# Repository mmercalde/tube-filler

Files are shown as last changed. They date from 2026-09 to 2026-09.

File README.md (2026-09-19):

# TUBE-FILLER

A small progressive-cavity grout pump built around a purchased German **D6-3**
rotor/stator set, to fill twelve **3 x 3 square PTR** posts, 6 m tall, with
sand/cement grout through a 1" hose and a 1" NPT port at each post base.

> The posts are **square PTR**. The pump barrel is **round tube**. They are two
> separate purchases that happen to share a nominal 3", and `params.py` keeps
> them in separate blocks with no cross-reference. The barrel is settled —
> McMaster 6045N87, bought and certified (§2a). The posts are not: measure them,
> and do not carry the barrel's certificate across.

Buildable with a chop saw, a drill press, a stick or MIG welder, hand tools and
a Bambu H2C. **No lathe, no mill** — every hole in this design is drilled,
hole-sawn or plasma/oxy cut, and every round part is a standard pipe or bar
size used as it comes.

---

## 0. Read this first

Four things decide whether this machine works, and only one of them is a design
choice:

| | |
|---|---|
| **The drive is now the binding constraint.** | A 900 W spade drill gives ~15 N·m continuous / 25 N·m burst at 250 rpm. At the *assumed* stator friction the duty needs 28.6 N·m and the drill is short. It works if — and only if — the stator's real running friction comes in at or below about **9 N·m**. Nobody has measured it. See §3 and `calcs` section 4. |
| **The pump is not the limit.** | The D6-3 is rated ≥ 30 bar; our duty is ~3 bar. Everything is sized for the *frame and joints* at **6 bar**, 3× duty, because that is what actually fails. |
| **The hose is the pressure limit.** | Grout is a Bingham fluid: loss is dominated by yield stress, not velocity. 8 m of 1" hose with a stiff mix costs more pressure than the whole 6 m of static head. `calcs` section 3. |
| **Nothing electrical protects this machine.** | A drill has no overload relay and no earthed frame. It does, however, stall far sooner than the 1.5 kW motor it replaced — which is the one way this conversion made the machine *safer*. §7. |

**RULES the design obeys, and that any modification must keep obeying:**

- Printed parts may **guide, feed, align and seal-assist**. They may **not**
  carry pressure or structural load. Steel contains pressure; rubber and rope
  seal it.
- Every wetted cavity opens for washout in under 5 minutes with two wrenches.
- All hardware metric where possible, from generic suppliers.
- Weld callouts suit a 3 mm wall. No full-penetration fantasies.

---

## 1. Repo layout

```
tube-filler/
  params.py            SINGLE SOURCE OF TRUTH.  All MEASURED INPUTS live here.
  bom.py               generates BOM.md from params.py
  calcs/pump_calcs.py  standalone; prints the one-page design summary + asserts
  cad/                 build123d models, all parametric on params.py
    build_all.py         <-- run this
    manifest.py          the print registry: drives BOTH the STL export and
                         out/print_manifest.md, so they cannot disagree
    coupons.py           the fit-coupon ladders (print these first)
    verify.py            geometry self-checks; nothing exports if one fails
    assembly.py          places every component at its params station; emits the
                         STEP assembly and the iso view, and runs the clash check
    jigs.py              printed fab templates (drill saddles, weld fixtures)
    ops.py               printed operational parts (cradle, screens, caps)
    _common.py  plates.py  printed.py  conrod.py  hopper.py  frame_drawing.py
  out/                 EVERYTHING GENERATED: STEP, STL, DXF, SVG, PDF
    machine_assembly.step  the whole machine, one named body per component
    assembly_iso.png       hidden-line isometric of the same
    fit_coupons.stl      20 fit coupons on one plate -- print before batching
    print_manifest.md    29 models / 53 parts: material, walls, infill,
                         orientation, consumable vs one-time jig
  BOM.md               generated
  test_plan.md         water -> cement milk -> grout, with abort criteria
  README.md            this file
```

To regenerate everything after changing a measured input:

```bash
make                  # everything
make calcs            # design summary + acceptance asserts
make assembly         # machine_assembly.step + assembly_iso.svg only
make clash            # interpenetration report, nothing exported
```

or just `make`. `cad/build_all.py` also re-runs the calcs into
`out/design_summary.txt` and rewrites `BOM.md`, so the drawings, the STLs and
the shopping list can never disagree with each other. Anywhere this README
quotes a number, `out/design_summary.txt` and `BOM.md` are the authority — they
are regenerated, this file is not.

> **CAD toolchain note.** The brief asked for CadQuery. CadQuery is installed
> on this machine but its OCP build is broken (`IVtkOCC` import error, missing
> VTK). The models are therefore written in **build123d 0.11**, which is the
> same OCP/OpenCascade kernel and the same lineage, and exports STEP, STL, DXF
> and SVG natively. Everything runs under `cadenv`:
> `~/cadenv/bin/python cad/build_all.py`.

---

## 2. MEASURED INPUTS — do this before you cut anything

Open `params.py`, Block A. Everything marked **TBD** is a placeholder: the
geometry around it is right, the number is a guess. Measure, edit, re-run.

`out/design_summary.txt` **section 11** prints the live list — 26 inputs, read
straight out of `params.py` at build time, so it cannot go stale and confirming
a part visibly shortens it.

| Input | How to get it |
|---|---|
| `stator_od`, `stator_len` | Calipers and a tape. Verify the vendor's 89.0 / 270.0. |
| `stator_inlet_bore` | The bore you can see at the stator's end face. Sets `adapter_bore` — get this right or you build a step for grout to hang on. |
| `stator_has_steel_jacket` | Is the rubber bonded inside a steel tube? If yes, set `stator_crush = 0.0`: the jacket is its own hard stop and the spacers must match the stator length exactly. |
| `stator_end_style` | Flat rubber face, or a moulded collar. Photograph both ends before you cut plate. |
| `rotor_joint`, `rotor_pin_dia`, `rotor_pin_eye_width` | Calipers on the rotor's drive head. If it is a *drill* head (a hex stub) rather than a *pin* head, see §5.3. |
| `rotor_free_len` | How far the rotor protrudes from the stator at the drive end. Sets how far into the barrel the con-rod reaches. |
| **`rotor_eccentricity`** | Two ways, both hand-tool: **(a)** lay the rotor in a V-block (two lengths of angle iron work), put a dial indicator on top, turn one full revolution: **TIR = 2e**, so `e = TIR/2`. **(b)** Caliper the stator bore at an end: it is a slot of width *d* and length *d + 4e*, so `e = (long axis − short axis)/4`. Do both; they should agree within 0.3 mm. |
| ~~`barrel_od`, `barrel_wall`~~ | **CONFIRMED — no longer measure-first.** McMaster **6045N87**, 3" OD × 0.120" wall, ID 2.76" = 76.2 / 3.05 / 70.1 mm, ERW ASTM A513 Type 1, 3 ft, $42.13, purchased and certified. The numbers in `params.py` did not change; their *status* did. Still put calipers on it when it lands — see §2a. Sets the barrel bore, the auger, the hopper slot and the barrel jigs. **Nothing about the posts depends on it.** |
| **`post_shape`, `post_side`, `post_wall`** | The twelve **posts**: square PTR, measured across the flats. **This is what sets the post volume and therefore the cement order** — see §3a. Separate stock from the barrel; do not assume they measure the same. |
| **`drill_body_dia`** | Calipers on the round gearcase section just behind the chuck collar, at its widest. Sets the printed cradle. |
| `drill_body_len`, `drill_chuck_depth`, `drill_chuck_body_len`, `drill_aux_offset` | Tape and calipers on the drill. These four place the cradle and the torque lug along the machine axis; get them wrong and the chuck is not coaxial with the stub. `verify.py` checks the result lands on the pump axis. |
| `drill_aux_handle_dia` | The auxiliary-handle collar. The steel torque lug is cut half-round to it. |
| `drill_T_cont`, `drill_T_burst` | The drill's continuous and burst torque at 250 rpm. Nameplate figures are optimistic; if you can, measure. |
| `post_port_height`, `post_vent_from_top` | Where the 1" port and the vent go on each post. The printed post jigs are built from these, so 24 holes come off two prints. |
| `post_side` (or `post_od` if round) | The post jigs parametrize on this. Stock that measures 75.4 instead of 76.2 costs one reprint, not a scrapped hole. Setting `post_shape` switches both post jigs between a corner channel and a V-saddle. |
| `bucket_rim_od` | Your 5-gal bucket. Sets the sand-screen frame. |
| `printer_x/y/z` | Your H2C build volume. `verify.py` refuses to emit a part that will not fit. |
| **`print_clearance`** | **Measured, not guessed — from `out/fit_coupons.stl`.** One number (0.25 mm diametral by default) governs every printed feature that has to fit real steel. Print the coupon ladder, find the rung that fits, put it here. See §5.0. |
| `print_interference` | Same idea, opposite direction: the oversize on the NPT dust-cap barbs, which must grip. Its own coupon rung. |

---

## 2a. Receiving check — the barrel lands first

The barrel is the first part of this machine to exist. Certified is not the
same as measured, and everything printed that touches the barrel — the two
end-ring jigs, the hopper-slot wrap jig, the saddles — is cut from these two
numbers. Five minutes with calipers before the tube is put down somewhere.

1. **ID at both ends.** Expect **70.1 mm** (2.76"). Measure the *bore*
   directly, not OD minus twice a wall you read at one spot: the bore is what
   the auger runs in, and `auger_od` is derived from it. Take two readings 90°
   apart at each end — ERW tube is not perfectly round near the cut.
2. **OD at two spots**, one near each end. Expect **76.2 mm**. This is the
   number the printed jigs and the two barrel saddles register on.
3. **Wall at both ends.** Expect **3.05 mm** (0.120"). A513 wall tolerance is
   wide, so this is the one most likely to read off.
4. **Find the ERW seam and mark it.** Run a fingernail or a rod down the bore
   from each end: the internal seam ridge is easy to feel and hard to see. Mark
   its clock position on **both** end faces with a paint pen and carry a line
   along the outside of the tube. You will need it twice — when you mark out
   the hopper slot (§5.3) and if you decide to flap-wheel the ridge.
5. **Keep the offcut.** 3 ft is 914 mm; the barrel takes 600. The ~310 mm left
   over is the only spare 3" round tube on site — do not cut it up for
   brackets.

If a number reads off: **edit `params.py`, re-run `make`, reprint the barrel
jigs.** Nothing is scrapped, because every part that registers on the barrel is
printed and every one of them comes *after* this check. That is the whole
reason the jigs are plastic.

Do not bore, hone or ream the barrel to clean up the seam. The wall is 3.05 mm
and it is a pressure boundary — see the fab note in `BOM.md` §2.

---

## 3a. Square posts, and what that does to the cement order

The posts are 3 x 3 square PTR, not round tube. A square bore of the same
nominal size holds **27% more**:

| | bore area | per post | x 12 |
|---|--:|--:|--:|
| square PTR, 76.2 across flats, 3.05 wall | 70.1 x 70.1 = 4914 mm² | **29.5 L** | **354 L** |
| round tube, 76.2 OD, 3.05 wall | ø70.1 = 3859 mm² | 23.2 L | 278 L |
| the brief's assumption | — | ~27 L | 324 L |

So the job is **354 L**, not the brief's 324 and certainly not the 278 you would
get by assuming round tube — a 76 L swing, which is about a sack and a half of
cement. `calcs` section 1 prints the correct figure from `post_shape`,
`post_side` and `post_wall`, flags the difference against the brief, and
section 10 sizes the cement, sand and water from it.

**Measure the wall before you order cement.** Under-ordering stops you
mid-post, and a post you stopped filling is a post you have to chase with a
hand pump.

Two things square PTR makes *easier*, worth knowing before you cut:

- the 1" NPT half coupling welds to a **flat face** — no saddle cut, no
  fish-mouth, and a hole saw that will not skate;
- two adjacent flat faces locate a jig completely, which is why the post jigs
  are now L-section corner channels rather than V-blocks (§5.0).

---

## 3b. The drill question, answered honestly

`calcs/pump_calcs.py` section 4 prints this in full. The short version:

| stator friction | total at duty | 900 W drill |
|--:|--:|---|
| 5 N·m | 11.0 N·m | runs, with margin |
| 6.5 N·m | 12.5 N·m | runs, no margin |
| 9 N·m | 15.0 N·m | at the continuous limit |
| 15 N·m | 21.0 N·m | breakaway only, will overheat |
| 22.6 N·m (assumed) | 28.6 N·m | **will not turn it** |

The 22.6 N·m in `params.py` is a placeholder inherited from sizing a 1.5 kW
motor, where it barely mattered. It has never been measured. Two things say the
real number may be much lower:

- the vendor sells a **drill-head rotor variant** of this very set, which means
  the manufacturer expects a drill to drive it;
- interference torque on a PC stator falls substantially once the rubber has
  bedded in and is wetted.

So the answer is not "yes" and it is not "no". It is: **measure it on water
before you mix a single bag of cement** — `test_plan.md` W-4 — and put the
measured number into `params.py`. The three levers, in order of effect:

1. **Break-in spacers.** A second set of tie-rod spacers cut to
   `stator_len − 0.5` instead of `stator_len − 2.0`. Run cement milk for 30
   minutes on those, then swap to the service set. This is the big one and it
   costs four pipe offcuts. See §6.1.
2. **Run the gland weeping**, not dry. Worth ~2.5 N·m — a sixth of the drill's
   whole continuous budget.
3. Shorten the hose, thin the mix. Worth ~1 N·m. Least effect, because
   friction, not pressure, dominates this budget.

If the measured friction still will not fit, the motor and reducer go on the
**same hex stub** with no change to the pump. See §11.

---

## 4. How the machine works

Hopper → barrel → feed auger → adapter plate → stator → discharge head → valve
→ hose → post.

- **Hopper** (44 L, wall angles 69° and 71°) feeds down through a
  200 × 50 slot into the top of the barrel. One hopper load is 1.5 posts.
- **Barrel**: 600 mm of the owner's 3" tube. The drive shaft enters the rear
  through a **packed gland** — greased graphite rope in a steel stuffing box,
  with a lantern ring fed by a grease nipple. Not a lip seal. Lip seals die in
  minutes on grout.
- **Feed auger**: printed segments, cross-pinned to the shaft, sized to deliver
  more than the stator's swallow rate. A PC pump must never starve.
  Its OD, hub, pitch and segment length are *solved* in `params.py` from the
  barrel bore, the shaft diameter and the overfeed target — change the barrel
  and the auger follows. The pitch is snapped so a whole number of pitches
  exactly spans the barrel, which is what keeps every cross-pin hole on the
  same clock angle and every segment interchangeable.
  **The overfeed is checked at the auger's worst station, not on its average**
  — see §4.2. A screw that starves anywhere starves.
- **Adapter plate**, welded to the barrel front. Washout face #1.
- **Stator** hangs off the front, compressed lengthwise between the adapter
  plate and the discharge head by 4 x M10 tie rods. **No radial crushing.**
- **Discharge head**: rear plate + chamber ring + cap + 1" NPT half coupling.
  Washout face #2. Carries the pressure gauge boss.
- **Drive**: 1/2" spade-handle paddle drill → **rear hex stub** → 35 mm shaft on
  two UCP207 pillow blocks → shaft tongue → **con-rod with two forks at 90°** →
  rotor. No motor, no reducer, no coupling.
  The drill is *captured, not held*: its aux-handle collar bears on a **steel
  torque lug** welded to a braced steel upright, and a printed saddle clamps the
  body down. The operator's only job is the trigger.

### 4.1 The two ideas that make this design work

**Hard-stop spacers.** The four tie rods do not clamp the rubber. They clamp
four lengths of 3/4" sch40 pipe cut to `stator_len − stator_crush`. The rubber
sits inside that steel sandwich and is squeezed exactly `stator_crush` mm, no
matter how hard you pull the nuts. **Cut all four spacers together, in one
setup, to ±0.2 mm.** Over-crushing a PC stator closes its bore, spikes the
interference torque, and burns the rubber in one shift. This design makes that
failure mechanically impossible.

**Two forks at 90°.** The rotor of a 1:2 progressive-cavity pump does not just
orbit — its axis precesses on a cone. A single cross pin is a one-degree-of-
freedom hinge and cannot follow that. The con-rod therefore carries a fork at
each end with the pin axes **perpendicular to one another** (a Cardan pair),
and both pin bores are drilled 0.5 mm oversize so each joint is deliberately
sloppy. Grease it and put a bicycle inner-tube boot over it. If you build the
forks parallel, the joint binds and tears the rotor head off.

### 4.2 The pin boss, and why an average is not a check

Each auger segment is driven by a 6 mm cross pin, and the pin needs more
plastic around it than the 4.5 mm hub wall. That local boss sits *in the feed
channel*, and for three revisions it was a plain Ø56 × 22 cylinder because it
was sized for the pin and nothing else looked at it.

Ø56 in a Ø70.1 bore leaves **61%** of the plain-hub free area. `calcs` section
5 was reporting an overfeed of 1.54× — correctly, for the plain hub — while the
**local** overfeed at each of the three boss stations was **0.58×**. The screw
metered above the stator's swallow everywhere except the three places it
mattered, and starved there. The pump sees the pinch, not the mean.

The boss is now Ø48 and shaped:

- **Area.** Ø48 swept, which is capped by a hard gate — local overfeed ≥ 1.15×
  at *every* z along the auger, walked at 0.25 mm in `calcs` section 5b. That
  gate bites at Ø49.2. (Ø50 reads 1.09× and does not clear it.)
- **Shape.** A faired lens rather than a cylinder, so it sheds instead of
  damming: a double cone axially into a short land, and in plan an ellipse with
  its major axis on the pin, blended flush into the hub at ±90°. Material ends
  up only where the pin bears; the two quarters of the channel that carry no
  load stay at full hub diameter. **The gates take no credit for the lens** —
  they are computed on the circle it sweeps.

The fairing is axial, which is the along-channel component of the helix.
Skewing the lens to the true helix angle would make the boss asymmetric about
the pin, and that is the one thing it may not be: both bearing patches have to
match or the pin cocks and digs in on one side.

Pin bearing at duty is 0.62 MPa against 40 MPa allowable for solid-printed
PETG — a 65× margin. At a full jam it is 2.6×, and that is deliberate: a jam is
bounded by the drill stalling, and the boss is the cheapest thing in the chain
to give way. If it does, the segment spins free, the pump starves and you
notice; the pin stays captive in the shaft and nothing loose enters the barrel.

Worth knowing before anyone thickens it again: the two constraints have nearly
converged. The feed gate caps the boss at Ø49.2, and carrying a full-burst jam
at 3× would want about Ø49.8. **No boss diameter does both.**

---

## 5. Build order

Nothing here needs a machine tool. Rough times are for one person.

### 5.0 Print the fit coupons first (before you print anything else)

`out/fit_coupons.stl` is one plate, about an hour: **twenty coupons, four
ladders of five rungs**, each rung embossed with its own value.

| tag | coupon | try it on | want |
|---|---|---|---|
| `A` | auger **cross-pin hole**, in a hub ring on the shaft | the real 35 mm shaft and a 6 mm pin | pin pushes through by hand, no slop |
| `P` | post-jig corner channel | a real square PTR corner | both faces touch, no rock, comes off by hand |
| `B` | template drill bushing | the real 11 mm bit | spins freely, no perceptible wobble |
| `C` | dust-cap barb | a real 1" NPT half coupling | firm thumb to seat, stays put upside down |

Put the values that fit into `print_clearance` and `print_interference` in
`params.py`, re-run `make`, and only then batch. **Every printed mating feature
in the project is derived from those two numbers**, so one measurement retunes
all 53 parts — the auger cross-pin holes, the jig register faces on tube and on
square post, the drill bushings, the cradle on the stator, the saddle on the
drill body, the gland follower, the PTR weld fixtures.

`B` is the tightest use in the project: if one rung is snug there and loose
everywhere else, that rung is the one that decides.

Each coupon prints in the same orientation as the part it stands for — the
auger bore vertical, the corner channel on its 45° corner, the bushing flat. A
fit measured in one orientation does not transfer to another; first-layer
squish and seam placement are not the same on a 45° face as on a flat one.

A wrong clearance found on part 40 of 53 costs several kilos of filament and a
weekend. This plate costs an hour.

> **Not everything printed is a "fit".** Two numbers are deliberately outside
> the coupon loop, and neither is tuned from a coupon result:
>
> - `running_clearance` (0.80 mm) — the gap in the gland follower and lantern
>   ring around the *rotating* shaft sleeve. A gap, not a fit.
> - `auger_bore_clear` (0.50 mm) — the auger hub bore over the 35 mm shaft,
>   fixed at a loose slide. The 6 mm cross pin locates each segment and carries
>   the drive; the bore's only job is to go on and come off a wet, gritty shaft
>   with five segments to line up. Dialling the jig bushings in tight used to
>   shrink this bore with them, which is the one place tight buys nothing.
>
> So on rung `A`, read the **cross-pin hole**. The ring's bore steps with the
> rung too — it is the project's reference *printed bore over round steel*, and
> a ring you can feel on a real shaft is how you judge a rung at all — but the
> auger's own bore is not read from it.

### 5.1 Print the jigs next (before you cut any steel)
`out/print_manifest.md` lists all 28 models with material, walls, infill,
orientation and whether each is a consumable or a one-time jig. Print order is
in that file. In particular:

- `gauge_tie_rod_spacers` **before** you cut the spacers.
- `jig_barrel_hopper_slot`, `jig_barrel_rear_flange`, `jig_barrel_tie_rods` and
  the three 1:1 flange templates before you touch the barrel or the plate.
- `jig_post_port` / `jig_post_vent` before you touch the twelve posts — two
  prints, 24 holes, all at the same height without reading a tape 24 times.
  On square PTR these are **L-section corner channels**: they register on two
  adjacent faces, which locates a square section completely. A V-block cannot —
  a vee on a flat face touches two arbitrary lines and rocks. Each jig has the
  bushing centred on the face it drills and a datum leg to the post end, so the
  distance from the end to the hole is the jig, not a tape measure.
- `fixture_ptr_corner` / `fixture_ptr_tee` before frame day. **Both are
  sacrificial**: they tack, then they come off. Weld out with one fitted and
  you melt it into the joint.

No printed jig stays on the machine and none is in the pressure path.

### 5.2 Frame (one day)
Cut list and weld notes are on `out/frame_weldment.svg` (also .png/.pdf).
Tack the whole skid, check the diagonals equal within 2 mm, then weld out.
**Weld the top rails last, with the barrel clamped in its saddles** — the
barrel, not the frame, is the alignment datum for the whole machine.

### 5.3 Barrel and plates (one day)
1. Cut the barrel to 600 mm from the 914 mm McMaster length, square both ends.
   Keep the ~310 mm offcut.
2. Wrap `barrel_slot_wrap_template.dxf` around it, **clocked 180° from the ERW
   seam you marked on receiving** (§2a), centre-punch, chain-drill and grind
   the 200 × 50 slot. The template's width is the **developed arc** (54.5 mm),
   not the 50 mm chord — cut to the template, not to a tape. The slot is the
   one place the seam ridge could pack grout; everywhere else it is a rib in a
   70.1 bore and the auger clears it by 4 mm. With the slot open, a flap wheel
   on an extension will reach most of the seam if you want it knocked down —
   knock it down, do not try to remove it.
3. Cut and drill the plates from the DXFs. `adapter_plate.dxf` carries a
   dashed **SCRIBE** layer showing the barrel OD circle — scribe it, don't cut
   it.
4. Weld the adapter plate to the barrel front and the rear flange to the back.
   Check both faces square to the bore with a square and a straightedge before
   the weld cools. **Everything else is shimmed to these two faces.**
5. Weld the throat collar over the slot, then the hopper on top of the collar,
   then the rim bar.
6. Weld the discharge head as a stack: rear plate, chamber ring, cap, half
   coupling, gauge boss. Keep the bores concentric — a 20 mm bolt through them
   while tacking works.

### 5.4 Drive train (one day)
1. Cut the 35 mm shaft. Drill the auger cross holes at the spacing given in
   `BOM.md` (with the shipped defaults: five holes at 130/130/130/130/65) using `auger_pin_drill_jig.stl` — the jig clamps to
   the shaft and puts every hole on the same clock angle. Drill the 8 mm
   drill-stub hole at the rear.
2. Slot the shaft nose 12 mm wide × 55 deep with a cutting disc, insert the
   shaft tongue, fillet weld both sides.
3. Con-rod: cut the 32 mm bar to 91 mm, weld two 8 mm ears on each end.
   **Rotate the second pair 90° from the first.** Drill both pin holes 0.5 mm
   over the pin diameter, on the drill press, with the bar in a V-block.
4. Stuffing box: weld the 2-1/2" pipe into the rear cover, drill the 8 mm
   grease hole, weld the 1/8" half coupling over it, fit the zerk. Weld the two
   M10 gland studs.
5. Bolt the rear cover on with a 3 mm nitrile gasket. Slide on the shaft
   sleeve, then pack: **2 rings — lantern ring — 2 rings — printed follower —
   gland plate.** Stagger every ring joint 90°. Nip the nuts finger tight plus
   a flat; the gland is meant to weep slightly when running.
6. Mount the pillow blocks on the slotted sub-plate. Lock both collars; the
   **rear** one takes the rearward thrust.
7. Hex stub: cross-pin the 1-1/4" pipe sleeve to the shaft rear, plug-weld the
   1/2" hex bar. Check it runs true — spin the shaft and watch the hex.
8. Drill station: weld the braced upright, then **one 10 mm bracket** on top of
   it — a half-round torque lug at its front edge, cut to the *measured*
   aux-handle collar, and a flat behind it for the printed saddle. One plate,
   two jobs; the lug is the only torque path. Bolt the printed saddle down
   through its slots, sit the drill in, chuck it on the stub, and shim until
   the drill runs with no side load on the stub. **Weld both drill braces** —
   unbraced, the upright sags 2.4 mm under the 1160 N torque reaction and the
   drill cocks off the stub axis.

   The saddle is only as long as the drill body behind the collar
   (`drill_body_len − drill_aux_offset`), which on a typical spade drill is
   about 46 mm. Sizing it at 130 put it straight through the torque lug — the
   assembly clash check caught that, and `cradle_plate_l` now follows the
   measured drill.

**If your rotor has a *drill* head (hex) instead of a pin head:** you still
need the 2-DOF articulation. Do not chuck a hex socket straight to the shaft.
Build the same con-rod, and make the front end a hex socket by welding a
standard nut of the measured across-flats size inside a short tube — then the
*rear* fork alone provides only 1 DOF, so add a second cross pin at 90° in the
socket tube. Set `rotor_joint = "drill_hex"` and `rotor_hex_af` in `params.py`.

### 5.5 Printing
Everything: material, walls, infill, orientation, quantity and print order is
in **`out/print_manifest.md`** — 29 models, 53 parts, roughly 7 kg of filament
across coupons, jigs, wetted parts and operational parts.

Three rules hold across all of them:

- **Coupons before batch.** §5.0. Two numbers in `params.py` drive every
  printed fit; measure them once.

- **No supports on anything.** Every model is emitted in its print orientation
  and every overhang is at 45° or steeper. The auger flight self-supports (97%
  layer-to-layer overlap); the clamp jigs are 90° V-blocks; the funnel leans
  14° from vertical; horizontal bores are teardropped.
- **Printed parts guide, feed, align, screen, cover and seal-assist. They never
  contain pressure and never carry structural load.** The drill cradle is the
  case to be explicit about: it clamps, and the torque goes drill collar →
  steel lug → steel upright → braces → skid.

Print the spare auger set and the spare gland parts *now*. They are consumables
and you will want them on a Saturday.

---

## 6. Operating procedure

### 6.1 Before the first powered start of a NEW stator — do not skip this
A dry PC stator has enormous breakaway friction and will burn in seconds.

1. Wet the stator bore with soapy water or cement milk. Pour some in and swill it.
2. Put a wrench on the coupling (or the drill stub) and **turn the pump through
   two full revolutions by hand.** If you cannot turn it by hand, the stator is
   over-crushed or the rotor is wrong — stop and check the spacer length.
3. Only then pull the trigger, and start in the drill's LOW range at part
   throttle. If the drill bogs immediately, stop: you are on the wrong spacers
   or the stator is over-crushed.

Repeat step 1 and 2 after every wash-out, every time.

### 6.2 Running
1. Hose connected, whip checks on, discharge valve **open**, bypass valve closed.
2. Prime with 5 L of cement milk (cement + water, no sand) — it lubricates the
   hose wall and stops the first grout from bridging.
3. Start the pump. Load the hopper. **Never let the hopper level drop below
   the top of the barrel slot** — a starved PC pump cavitates, knocks and eats
   its stator.
4. Watch the gauge. Normal running is 2–4 bar. **6 bar is the red line.**
5. Pump until grout runs from the vent at the top of the post.

   > ### VALVE BEFORE TRIGGER
   > **Close the discharge ball valve first. Then release the trigger.**
   > In that order, every single time.
   >
   > A drill freewheels the instant you let go — there is no gearbox, no brake
   > and nothing holding the rotor. The 1.24 bar column of grout standing in
   > the post will drive the rotor backwards and drain itself into the hopper,
   > and you will not see it happen: the vent simply stops weeping and the top
   > of the post is hollow. On the motor version a 7.5:1 worm at least slowed
   > this down. On a drill there is nothing at all between the column and the
   > hopper except that ball valve.
6. Fill time is ~2.4 min per post; twelve posts is ~29 min of pumping.

### 6.3 If it stalls or the pressure climbs
1. **Open the bypass valve.** That is the relief valve. Do it first.
2. Release the trigger.
3. Flick the drill into reverse and give it a second or two — a paddle drill
   reverses on a switch, which is one thing this drive does better than the
   motor version. A few seconds in reverse clears most bridges.
4. Never "help" it by closing the discharge and squeezing harder. A drill will
   happily push the pump to 15 bar before it stalls, and the joints are built
   for 6.

---

## 7. Safety

- **The drill is the machine's best overpressure protection, and it is still
  not enough.** At low measured friction the drill stalls somewhere around
  15-20 bar; the 1.5 kW motor it replaced did not stall until ~140 bar. That is
  a genuine improvement. It is not a relief valve. The gauge and the bypass
  valve are still the safety system.
- **A drill has no overload relay and no earthed metal frame of its own.** The
  30 mA RCD is the only electrical protection on this build. Do not omit it,
  and test it with its own button before every session.
- **Never wedge or zip-tie the trigger.** The trigger is the emergency stop and
  the only thing standing between a blockage and a burst hose.
- The drill is captured in the cradle for exactly one reason: so nobody is
  holding 25 N·m of reaction torque by hand when the pump snatches.
  - 0–16 bar glycerin gauge, **flush-diaphragm** isolator, mounted in the
    operator's eyeline. Paint a red band at 6 bar.
  - 1" manual bypass ball valve, discharge head back to the hopper, short line.
  - Hose rated ≥ 40 bar working. **Crimped ends only. Never a worm-drive hose
    clamp on grout.** Whip checks at every coupling.
  - 30 mA RCD on the supply. There is no overload relay on this build --
    a drill has none, and its own thermal cutout protects the drill, not
    the pump.
- 20 A circuit, 2.5 mm² (12 AWG), **30 mA RCD**. The machine is wet and steel.
- The grate is bolted on and stays on while the machine runs. There is an auger
  under it.
- Never break a hose coupling before the gauge reads zero.
- Wet cement burns skin. Gloves, eye protection, long sleeves.
- Grate note: **the grate is a tramp guard, not a sieve.** A 3 mm grate over a
  hopper of wet grout blinds instantly. Size the sand to ≤ 3 mm **at the sand
  pile, through a real screen, before it goes in the mixer.** The grate's job is
  to keep stones, trowels and hands out of a running auger.

---

## 8. Flush procedure

**Within 20 minutes of the last post, and before any break longer than 20
minutes.** Two 17 mm wrenches, a bucket, a garden hose, a bottle brush, a
grease gun.

1. Stop the pump. **Open the bypass valve** and confirm the gauge reads zero.
2. Close the discharge ball valve. Break the hose at the machine, drop the far
   end in the wheelbarrow, and push a wet sponge ball through the hose with
   water. Recover the ~4 L of grout in it.
3. Scrape the hopper out into the barrow. Do **not** wash hopper grout down
   into the barrel — you are trying to get grout out, not in.
4. Refit the hose. Fill the hopper with 20 L of clean water, open the discharge
   valve, and run at speed into the barrow until it runs clear (~2 min).
5. Open the bypass halfway and run another 10 L to clear the bypass line and
   its return to the hopper. Close the bypass.
6. Stop. Loosen the four tie-rod nuts and slide the discharge head, stator and
   spacers forward off the adapter plate as one unit.
7. Hose out, and brush: the stator bore, the discharge chamber, the adapter
   plate bore, the barrel (through the adapter bore *and* through the open
   hopper throat).
8. Three strokes of the grease gun on the gland zerk, until clean grease shows
   at the follower. This purges the lantern ring.
9. Unscrew the gauge isolator, wipe the diaphragm, refit.
10. Reassemble wet: gaskets in, stator on, nuts to **20 N·m**. Leave a litre of
    water standing in the barrel until next use.

**End of job, or before the machine stands more than 48 h — additionally:**

11. Unbolt the four rear-cover bolts and the pillow-block sub-plate, draw the
    whole drive train rearward out of the barrel. Wash the auger segments and
    the shaft. Inspect the sleeve. Repack the gland if the follower's shoulder
    has reached the box rim.

### 8.1 Every wetted cavity, and the step that clears it

| Cavity | Cleared by |
|---|---|
| Hose, discharge valve, half coupling | 2, 4 |
| Discharge chamber | 4, 7 |
| Stator bore | 4, 7 |
| Adapter plate bore | 4, 7 |
| Barrel bore and auger flights | 4, 7 |
| Annulus in front of the gland | swept by the scavenger segment; 4, 7 |
| Hopper and throat collar | 3, 4 |
| Bypass line and its return | 5 |
| Gauge port and diaphragm | 9 |
| Packing stack and lantern ring | 8, 11 |
| Auger hub bore / shaft clearance | 11 |

If a step is skipped, the cavities in its row are the ones holding grout in the
morning.

---

## 9. Maintenance and wear

| Part | Life | Note |
|---|---|---|
| Stator | the real consumable | Never run dry, never over-crush, never starve. |
| Auger segments | a season, or one bad flush | Declared consumable. Keep a printed spare set. |
| Shaft sleeve | a season | 1-1/4" sch40 pipe, $3. It wears so the shaft doesn't. |
| Gland packing | ~40 h pumping | Repack when the follower shoulder touches the box rim. |
| Follower / lantern ring | with the packing | Reprint. |
| Coupling spider | years | Keep one spare. |
| Gaskets | every strip-down | 3 mm nitrile, cut with a hole saw and scissors. |

---

## 10. What to measure and feed back into `params.py`

The design's weakest assumption is `T_stator_friction = 22.6 N·m`. On the motor
it barely mattered. **On the drill it decides whether the machine runs at all**
(§3b). Measure it on the water test (`test_plan.md` W-4), put the real number
into `params.py`, and re-run `calcs/pump_calcs.py`. The verdict line at the
bottom will tell you PASS, MARGINAL or SHORTFALL — and the table in section 4
tells you what to do about each.

Also worth feeding back: `grout_tau0` (from the pressure the gauge actually
shows on the first post), and `auger_fill_eta` (from whether the pump surges).

The full standing list is `out/design_summary.txt` **section 11** — every TBD
left in `params.py`, grouped, generated at build time. It is currently 26
inputs in seven groups; the barrel came off it when 6045N87 was ordered.

---

## 10a. The assembly model, and the five things it caught

`cad/assembly.py` places every component at its `params.py` station — reusing
the same builders that produce the STLs and DXFs, never remodelling — and emits
`out/machine_assembly.step` with one named body per component plus
`out/assembly_iso.png`. The drill is in there too, as an envelope cylinder off
the measured drill dimensions, so the clearances you read are the real ones.

`verify.py` then intersects **every pair of bodies** and fails the build on any
shared volume that is not on `assembly.INTENDED_FITS` — a short, explicit list
(shaft-in-sleeve, auger-on-shaft, stator-on-cradle, fork-on-tongue, chuck-on-
stub, and the welded stacks). Run it alone with `make clash`.

Placing the parts is what proved the layout, and it was not clean:

| what the clash check found | why it mattered |
|---|---|
| The shaft nose sat 200 mm inside the space the con-rod needs. | `x_auger_front` was a hard-coded −30. The rotor position is set by the stator and nothing else can move, so the chain now runs **forwards** from the rotor: tip → pin → con-rod → tongue → shaft nose → auger. The auger is 371 mm, not 520, and the shaft got 200 mm shorter — which incidentally cut the unsupported overhang from 770 mm to 558 and the deflection from 1.90 mm to 0.68. |
| The stator cradle sat straight through two tie-rod spacers, and the strap through the other two. | Only ~3.5 mm of web fits between the stator and a spacer. Both parts now have closed circular channels at the spacer stations; the spacers slide out axially with the stator at washout, so a closed channel costs nothing. |
| The hex stub's 42 mm sleeve was inside the rear pillow block housing. | The shaft rear moved to −1000 and the blocks to −790 / −900. |
| The printed drill saddle ran straight through the steel torque lug. | There is only `drill_body_len − drill_aux_offset` of drill body behind the collar. The saddle is now sized from that, and lug and saddle share one welded bracket. |
| The stator strap duplicated the cradle's lower half. | It was modelled as a full arch from −r to +r. It now caps only the upper half, and prints valley-up so it needs no supports; the assembly flips it. |

Two smaller ones: the hex stub's weld plug sits *beyond* the shaft end, so the
chuck face is a plug thickness further back than `hex_free_len` alone implies;
and the top rails were set from the barrel OD when the **stator** is the fat
part — they were 6 mm inside it. Both are now derived.

None of these would have shown up in a part-by-part review. All five showed up
the first time the parts were put in the same coordinate system.

---

## 11. Upgrade path -- motor and reducer, same hex stub

Nothing about the pump changes. The drill drive was designed so this is a bolt-on:

| | |
|---|---|
| Motor | 1.5 kW 1-phase 220 V 4-pole, frame 90L, B14 FT130, 24 mm shaft |
| Reducer | NMRV-050, 7.5:1, 90B14 input, 25 mm output |
| Coupling | L-110 / ROTEX-38, one half bored to 12.7 mm A/F to take **the same hex stub**, the other 25 mm |
| Gives | 64 N·m at 193 rpm — a 2.1× margin even at the pessimistic 22.6 N·m friction |
| Costs | roughly $500, and about 1.2 m more PTR for the motor outrigger |

Prices and specs are in `BOM.md` §3b, deliberately kept **out** of the BOM
total. The frame drawing has no motor mount; adding one is an outrigger welded
to the left skid rail, because the NMRV's worm input sits at 90° to its output
and the motor therefore lies crosswise.

Two things to know before you spend the money:

1. **Fit the upgrade for torque, not for speed.** It runs the pump *slower*
   (193 rpm vs 250), so each post takes 2.4 min instead of 1.9.
2. **It takes the overpressure protection away again.** A 1.5 kW motor on a
   7.5:1 worm does not stall until ~140 bar — twenty times what these joints
   are built for — and no overload relay will trip first. If you fit it, the
   gauge, the red band at 6 bar and the bypass valve stop being good practice
   and start being the only thing standing between you and a burst hose.

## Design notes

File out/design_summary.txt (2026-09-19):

==============================================================================
  TUBE-FILLER -- D6-3 ROTOR/STATOR GROUT PUMP -- DESIGN SUMMARY
==============================================================================

==============================================================================
1  THE JOB
==============================================================================
  post bore (square)                     70.1 x 70.1 bore  76.2 sq PTR x 3.05 wall x 6 m
  post internal volume                             29.5 L  = side^2 x length
  x 12 posts                                        354 L  
  + hose hold-up                                    4.1 L  (8 m of 1")
  grout to mix (10% waste)                          394 L  
  ! The brief assumed ~27 L/post.  76.2 sq PTR x 3.05 wall holds 29.5 L -- MORE, not less.
    The job is 354 L, not 324 L -- a difference of 30 L (42 kg of cement).
    Square PTR is the reason: a 76.2 square bore is 4914 mm2 against 3859 mm2 for round
    tube of the same nominal size -- 27% more, and it all has to be
    mixed.  Under-ordering cement stops you mid-post.

==============================================================================
2  PUMP SPEED AND FLOW
==============================================================================
  drive                                       900 W drill  1/2" chuck on the hex stub, low range (0-550 rpm)
  rotor speed                                     250 rpm  direct -- no reducer, no coupling
  displacement                                 50 cm3/rev  vendor spec
  flow                                        12.50 L/min  
  fill time per post                             2.36 min  12 posts = 28 min of pumping

==============================================================================
3  PRESSURE REQUIRED AT THE PUMP OUTLET
==============================================================================
  static head                                    1.24 bar  6 m of SG 2.1
  hose friction (8 m of 1")                      1.66 bar  Bingham tau0=100 Pa, mu=0.1 Pa.s
  valve + port losses                            0.20 bar  
  TOTAL REQUIRED                                 3.10 bar  OK, >= 2 bar spec met
  hose velocity / Bingham Re               0.41 m/s / 219  laminar

  Sensitivity -- required outlet pressure [bar] vs grout stiffness & hose length:
      tau0 [Pa] |       4 m       6 m       8 m      12 m      20 m
      ----------+---------------------------------------------
             50 |     1.91     2.14     2.38     2.85     3.79
            100 |     2.27     2.68     3.10     3.92     5.58
            200 |     2.96     3.72     4.48     6.01     9.06
            300 |     3.64     4.74     5.84     8.05    12.46
  -> Hose length is the single biggest lever you control on site.
  -> Anything above 6 bar exceeds the joint design point:
     thin the mix or shorten the hose, do not push the pump harder.

==============================================================================
4  TORQUE BUDGET AND DRIVE MARGIN  -- 900 W DRILL
==============================================================================
  stator friction (ASSUMED)                      22.6 N.m  <-- A GUESS.  Measure it: test_plan W-4
  packed gland, run loose                         2.5 N.m  vs 5.0 at normal service preload
  feed auger                                      1.0 N.m  
  pressure @ 3.10 bar                             2.5 N.m  = dP.V/2pi
  TOTAL AT DUTY                                  28.6 N.m  (748 W at the rotor)

  drill continuous                               15.0 N.m  at 250 rpm
  drill burst / breakaway                        25.0 N.m  
  MARGIN ON CONTINUOUS                             0.53 x  want >= 1.30
  margin on burst                                  0.88 x  

  VERDICT: SHORTFALL AT THE ASSUMED FRICTION.  Read the next block before
  concluding the machine does not work -- the assumption, not the drill, is
  what is unproven.

  WHAT ACTUALLY DECIDES THIS -- the stator friction, which nobody has measured:

      stator friction |  total at duty |  drill cont.  |  drill burst  | stalls at
        [N.m]         |     [N.m]      |    15 N.m     |    25 N.m     |   [bar]
      ----------------+----------------+---------------+---------------+----------
                  3.0 |            9.0 |     OK        |     OK        |     23.2
                  5.0 |           11.0 |     OK        |     OK        |     20.7
                  6.5 |           12.5 |     burst     |     OK        |     18.8
                  8.0 |           14.0 |     burst     |     OK        |     17.0
                 10.0 |           16.0 |     burst     |     OK        |     14.5
                 15.0 |           21.0 |     burst     |     OK        |      8.2
                 20.0 |           26.0 |     no        |     no        |      1.9
                 22.6 |           28.6 |     no        |     no        |      0.0

  max stator friction, continuous                 9.0 N.m  (and only 7.0 with 1.30x margin)
  max stator friction, burst                     19.0 N.m  breakaway only
  ...if the gland is run tight                    6.5 N.m  the gland alone costs 2.5 N.m -- run it weeping

  So: the drill drives this pump if and only if the stator's running friction
  comes in at or below about 9 N.m.  That is not an unreasonable
  number for a wetted D6-3 at light interference -- and the fact that the vendor
  sells a DRILL-HEAD rotor variant says the manufacturer expects exactly this.
  But it is not proven.  Measure it on water (test_plan W-4) BEFORE mixing grout.

  Three levers, in order of effect, if the measured friction comes in high:
    1. BREAK-IN SPACERS.  Fit the 0.5 mm-crush spacer set and run cement milk
       for 30 min.  Interference torque falls as the rubber beds in.  This is
       the big one and it costs four pipe offcuts.
    2. Run the gland weeping, not dry.  Worth ~2.5 N.m.
    3. Shorten the hose and thin the mix.  Worth ~1 N.m -- least effect, because
       friction, not pressure, dominates this budget.
  If it still will not carry it: the upgrade path is 64 N.m at 193 rpm
  on the SAME hex stub -- see README section 11.

==============================================================================
5  AUGER FEED MATCH
==============================================================================
  flight annulus                                 1508 mm2  OD 62 / hub 44
  pitch                                           74.2 mm  = 1.19 x OD
  segments                               2 x 148 + 1 x 74  5 pitches span the barrel exactly
  swept volume @ eta=0.75                      77 cm3/rev  
  OVERFEED RATIO                                   1.54 x  target >= 1.30
  starves below fill factor                          0.49  print the 124 mm-pitch spares if it does

==============================================================================
5b  THE CROSS-PIN BOSS -- the worst station, not the average
==============================================================================
  Section 5 is an average over the plain hub.  A screw meters on its WORST
  station.  On this screw that is the boss around each drive pin, and these
  numbers walk the real core profile end to end at 0.25 mm.

  boss swept OD x axial                        48 x 30 mm  lens, 9 mm fairing each end
  boss plan form                               48 x 44 mm  major axis on the pin; flush with the hub at 90 deg
  local conveyed annulus at the boss             1219 mm2  vs 1508 open hub = 81%
  MIN LOCAL OVERFEED, all z                        1.25 x  gate 1.15; worst at z = -6.0 mm  PASS
  free area at the boss                               88%  of the plain-hub section; gate 75%  PASS
  largest boss the gate allows                    49.2 mm  fitted at 48

  WAS a plain cylinder at 56 x 22.  That is 61% of the open-hub free area and
  a LOCAL overfeed of 0.58 -- the screw metered 1.54x the stator's swallow
  everywhere except the three stations where it mattered, and starved there.
  A screw that starves anywhere starves: the pump sees the pinch, not the mean.

  Two changes, doing two different jobs:
    AREA  -- swept OD 48, capped by the 1.15x gate above, which bites
             at 49.2 mm.  (A 50 mm boss reads 1.09x and does NOT clear it.)
    SHAPE -- a faired lens, so it sheds instead of damming: double-cone
             axially into a short land, and in plan an ellipse with its major
             axis on the pin, blended flush into the hub at +-90 deg.  The
             two quarters of the channel that carry no pin load stay at full
             hub diameter.  The gates above take NO credit for the lens --
             they are computed on the circle it sweeps.

  CROSS PIN -- 6 mm steel bearing on printed PETG, allowable 40 MPa:
    wall each side of the shaft                   6.50 mm  projected bearing area 78 mm2, both walls
    at duty (1.0 N.m)                            0.62 MPa  margin 65 x  (want >= 3)  PASS
    if it JAMS (25 N.m burst)                    15.4 MPa  margin 2.6 x
    steel pin, double shear at jam                 13 MPa  vs ~400 for a spring roll pin -- not the limit

  The duty case is the gate and it passes by 65x.  The jam
  case sits at 2.6x, and that is deliberate: a jam is bounded by
  the drill stalling, and the boss is the cheapest thing in the chain to give
  way.  If it does, the segment spins free on the shaft, the pump starves and
  you notice -- the pin stays captive in the shaft and nothing loose enters
  the barrel.  Reprint the segment; it is already a declared consumable.
  Note the two constraints have nearly converged: the overfeed gate caps the
  boss at 49.2 mm, and carrying a full-burst jam at 3x would want
  about 49.8.  There is no boss diameter that does both, which is worth
  knowing before anyone thickens it again.

==============================================================================
6  AXIAL THRUST -- rotor pushes the shaft REARWARD
==============================================================================
  thrust at duty (3.10 bar)                         608 N  
  thrust at 6 bar +30%                             1532 N  sized on the stator inlet bore
  UCP207 axial capacity                            5100 N  = 0.2 x C
  margin                                            3.3 x  PASS
  Both pillow blocks get their collars locked; the REAR one takes the thrust.

==============================================================================
7  STATOR CLAMP -- tie rods over hard-stop spacers
==============================================================================
  gasket seating force                             5503 N  3 mm elastomer, y=1.4 MPa
  separating force @ 6 bar                         1299 N  
  minimum total clamp                              6802 N  = 1701 N/rod = 3.4 N.m
  RECOMMENDED preload                         10000 N/rod  = 20 N.m dry on M10 8.8
  rod stress at recommended                       172 MPa  vs 640 MPa proof (8.8)
  spacer stress                                    46 MPa  3/4" sch40, 217 mm2
  spacer cut length                              268.0 mm  = stator_len - crush; HARD STOP
  The spacers, not the rubber, carry the preload.  This is the whole point:
  you cannot over-crush the stator no matter how hard you pull the rods, and
  over-crushing is what kills a PC stator (bore closes, torque spikes, burns).

==============================================================================
8  DRIVE SHAFT DEFLECTION  (why the shaft is 35 mm)
==============================================================================
  unsupported overhang                             546 mm  front pillow block -> con-rod pin
  deflection, self weight                         0.09 mm  
  deflection, 150 N side load                     0.55 mm  
  TOTAL                                           0.64 mm  
  auger radial clearance                          4.00 mm  margin 6.2 x PASS

==============================================================================
8b  ROTOR ARTICULATION
==============================================================================
  eccentricity (measured input)                    4.5 mm  see README: V-block + DTI
  con-rod length                                   140 mm  
  length / eccentricity                              31.1  want >= 20
  joint angle swept                              1.84 deg  each fork gets 0.5 mm of slop; grease and boot it
  The two forks are at 90 deg to each other.  A single cross pin is a 1-DOF
  hinge; the rotor axis precesses on a cone, which needs 2.  Parallel forks
  will bind and tear the rotor head off.  Check this on assembly by hand.

==============================================================================
9  STALL, OVERPRESSURE AND WHAT PROTECTS THE MACHINE
==============================================================================
  drill stalls the pump at                        0.0 bar  -- it cannot turn it at all

      stator friction [N.m] |  pump stalls the drill at [bar]
      ----------------------+--------------------------------
                        3.0 |                       23.2
                        5.0 |                       20.7
                        6.5 |                       18.8
                        8.0 |                       17.0
                       10.0 |                       14.5
                       15.0 |                        8.2

  This is the drill's one clear win over the motor it replaced.  A 1.5 kW motor
  on a 7.5:1 worm does not stall until roughly 140 bar -- twenty times the
  6 bar these joints are built for.  A 900 W drill stalls far sooner, and at
  low measured friction it stalls inside or near the design envelope.  The
  drive is now part of the protection instead of a liability.

  It is still not ENOUGH protection.  Keep all of it:
    1. 0-16 bar glycerin gauge on the discharge head, red band at 6 bar.
    2. 1" manual bypass ball valve back to the hopper.  It is the relief valve.
    3. Hose rated >= 40 bar working, crimped ends, whip checks.
    4. 30 mA RCD on the supply.  A hand drill in a wet steel machine has no
       earthed frame of its own and no overload relay.  The RCD is the only
       electrical protection on this build -- do not omit it.

  AND the shutdown rule, which is different from the motor version:
    CLOSE THE DISCHARGE VALVE, THEN RELEASE THE TRIGGER.  In that order.
    A drill freewheels when you let go -- there is no gearbox holding anything.
    The 1.24 bar column in the post will drive the rotor backwards and
    drain itself into the hopper, and you will not see it happen.

==============================================================================
10  MATERIALS FOR THE POUR  (12 x square posts)
==============================================================================
  bore area per post                             4914 mm2  70.1 x 70.1 bore (square)
  volume per post                                 29.48 L  
  grout to mix                                      394 L  1:2 cement:sand, w/c 0.50
  cement                                           236 kg  = 4.7 sacks of 50 kg
  sand (sieved <= 3 mm)                            472 kg  
  water                                             118 L  
  hopper holds                                       44 L  = 1.5 posts per load

==============================================================================
11  STILL A GUESS -- the 26 TBDs left in params.py
==============================================================================
  Read live out of params.py, so this list cannot go stale.  Each one is a
  PLACEHOLDER: the geometry around it is right, the number is not measured.
  The barrel is no longer here -- McMaster 6045N87 is purchased and certified,
  76.2 OD x 3.05 wall, bore 70.1.

  D6-3 stator (vendor spec, verify with calipers)
    stator_inlet_bore          50.0 mm   bore visible at the stator end face
    stator_has_steel_jacket      False   True if the rubber is bonded inside a
                                         steel tube (changes the clamp calc)
    stator_end_style           "plain"   "plain" (flat rubber face) or "collar"
    stator_end_collar_od       89.0 mm   only used if stator_end_style=="collar"
    stator_end_collar_len       0.0 mm   collar length, if there is one

  D6-3 rotor
    rotor_joint             "pin_head"   "pin_head" or "drill_hex"
    rotor_pin_dia              12.0 mm   cross-pin diameter at the rotor head
    rotor_pin_eye_width        22.0 mm   width of the rotor's eye/tongue
    rotor_hex_af               19.0 mm   across-flats, only if "drill_hex"
    rotor_free_len             90.0 mm   rotor sticking out of the stator, drive
                                         end
    rotor_pin_inset            20.0 mm   pin centre back from the rotor's rear
                                         tip
    rotor_eccentricity          4.5 mm   = (stator minor bore - rotor dia)/2 ...
                                         see README "measuring eccentricity"

  PRIMARY DRIVE: 1/2" spade-handle paddle drill
    drill_body_dia             57.0 mm   BARREL/GEARCASE DIA at the cradle
                                         station. Calipers on the drill, just
                                         behind the chuck collar, at the widest
                                         round section
    drill_body_len            110.0 mm   length of that round section
    drill_aux_handle_dia       43.0 mm   auxiliary-handle collar dia (the Euro
                                         43 mm collar is common). The steel
                                         torque lug bears here
    drill_chuck_depth          40.0 mm   how deep the jaws grip
    drill_chuck_body_len       85.0 mm   chuck front face to gearcase nose
    drill_aux_offset           60.0 mm   gearcase nose to aux-handle collar

  THE TWELVE POSTS
    post_side                  76.2 mm   square: outside across the flats
    post_od                    76.2 mm   round only; ignored when square
    post_wall                  3.05 mm   cal-11 nominal 3.05

  Torque budget (see calcs for the breakdown)
    T_stator_friction         22.6 N.m   dry-ish rubber drag, RPM-independent. A
                                         GUESS until the water test -- test_plan
                                         W-4

  3D printer
    printer_x                 350.0 mm   confirm against the H2C spec
    printer_y                 320.0 mm
    printer_z                 325.0 mm

  misc measured inputs for the printed jigs
    bucket_rim_od             295.0 mm   5-gal bucket outside rim dia

  Four of these decide whether steel gets cut the way it is drawn today:
    T_stator_friction  -- section 4.  The whole drive question.  Water test first.
    rotor_*            -- the con-rod chain and every x-station behind it.
    stator_end_style / _has_steel_jacket -- sets stator_crush and the spacer cut.
    drill_*            -- the cradle and torque lug stations; verify.py re-checks.
  The rest cost a reprint, not a re-cut: post_* sizes the cement order (section
  10) and reprints two jigs, printer_* only gates what fits the bed, and
  bucket_rim_od is one sand screen.

==============================================================================
ACCEPTANCE CHECKS
==============================================================================
  [PASS]  delivery pressure >= 2 bar
  [PASS]  auger overfeed >= 1.30x
  [PASS]  thrust margin >= 2x
  [PASS]  shaft deflection < clearance/1.5
  [PASS]  tie-rod preload below proof
  [PASS]  hose flow laminar
  [PASS]  one hopper load >= one post
  [PASS]  con-rod length >= 20 x ecc
  [PASS]  auger local overfeed >= 1.15x at EVERY z
  [PASS]  auger free area >= 75% of open hub at every z
  [PASS]  auger pin bearing margin >= 3x at duty
  [PASS]  no dead annulus at the gland
  [SHORTFALL]  drive margin on continuous torque (0.53x, want 1.30x)

  The drive line is a VERDICT, not a gate.  It is reported and the build
  proceeds, because the input it depends on (T_stator_friction) is a guess
  and refusing to emit CAD over a guess helps nobody.  Everything else is
  a hard check and does gate the build.

  All hard criteria met.  DRIVE: SHORTFALL -- see section 4.
==============================================================================

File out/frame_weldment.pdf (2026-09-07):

## TUBE-FILLER -- FRAME WELDMENT

All members PTR 51 x 51 x 3.05 (2" square, cal-11). Dimensions in mm. BUILD TO THE NUMBERS, NOT THE PICTURE.
Machine datum x=0 is the FRONT FACE of the adapter plate. +x is toward the discharge. z is up from the ground. NO MOTOR: a 1/2" paddle dril

VIEW A -- SIDE ELEVATION (near frame + centreline drill station)

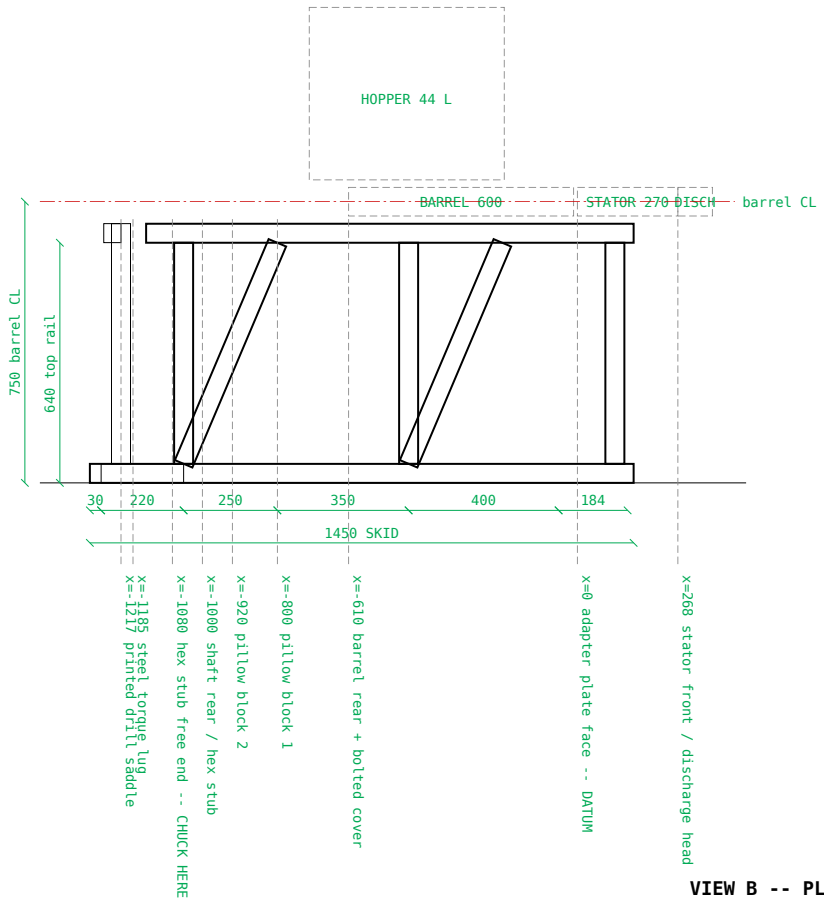
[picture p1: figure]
BARREL 600; STATOR 270 DISCH; HOPPER 44 L; barrel CL; 1450 SKID; x=-1080 hex stub free end -- CHUCK HERE; x=-1000 shaft rear / hex stub; x=-920 pillow block 2; x=-800 pillow block 1; x=-610 barrel rear + bolted cover; x=0 adapter plate face -- DATUM; x=268 stator front / discharge head; 640 top rail; 750 barrel CL

## x=-1217 printed drill saddle x=-1185 steel torque lug

VIEW B -- PLAN (skid heavy, top rails light)

549

32
NO MOTOR, NO REDUCER, NO COUPLING. The drill chucks straight onto the hex stub. Operator stands at +y, one hand on the trigger. The frame holds the drill.

CUT LIST (squ
QTY LENGTH MEMB
2 1450 skid rai
2 1300 top rail
2 697 drill bra
1 641 drill upr
4 640 knee brac
6 589 leg PTR 5
6 549 skid cros
3 549 top cross
1 220 drill rai
1 46 cradle out
18.8 TOTAL PTR

WELD NOTES (3.0
1. 4 mm fillet
2. 7018 at 80-9
through -- the
3. Tack the who
4. Weld the top
frame, is the a
5. Barrel saddl
21 mm tall, on
Top rails are s
stator cradle i
6. Pillow-block
so the whole dr
7. Lifting eyes
8. DRILL STATIO
a half-round to
43 mm aux-handl
carrying the pr
saddle clamps a
upright sags 2
9. Paint everyt

9/6/26, 5:28 PM

file:///home/michael/tube-filler/out/frame_weldment.svg | 1/1

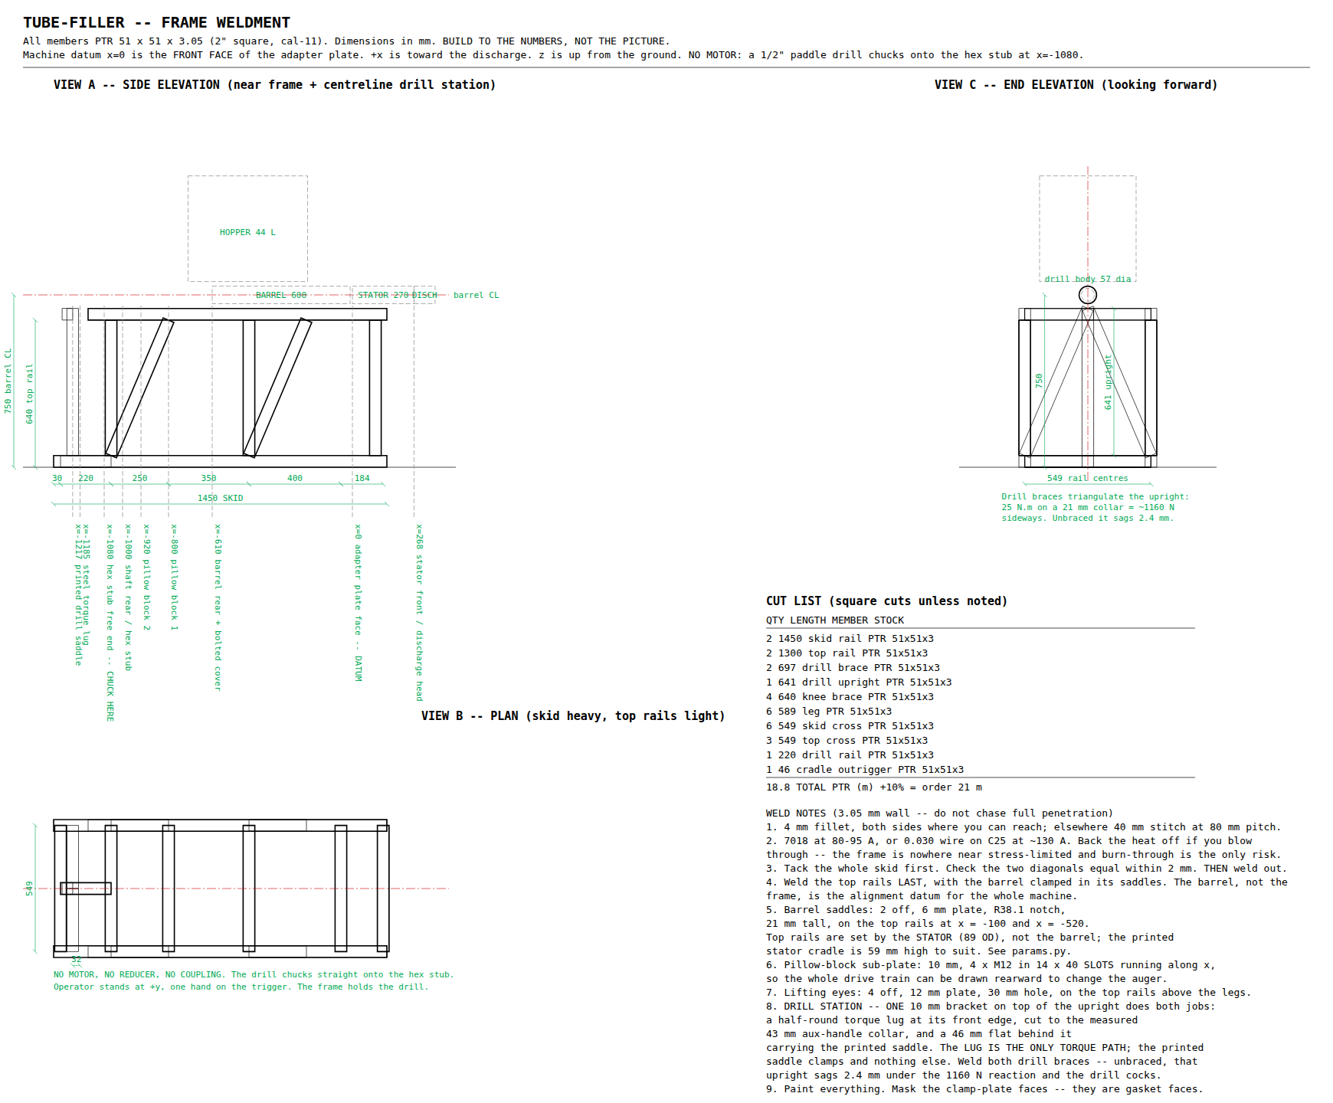
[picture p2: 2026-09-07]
out/frame_weldment.png

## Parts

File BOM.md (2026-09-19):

# BOM -- TUBE-FILLER

<!-- GENERATED by bom.py from params.py.  Do not edit by hand: run `python cad/build_all.py`. -->

Prices are 2026 order-of-magnitude estimates in USD for **one machine**, for budgeting only.
Quantities and every dimension below come straight from `params.py`, so they cannot drift
from the CAD.

## 1. Purchased

| Item | Qty | Spec | US source | MX equivalent | Unit | Ext |
|---|--:|---|---|---|--:|--:|
| Barrel stock -- ROUND tube (PURCHASED, CERTIFIED) | 1 | McMaster **6045N87** Multipurpose Low-Carbon Steel Round Tube, 3" OD x 0.120" wall, 2.76" ID (76.2 / 3.05 / 70.1 mm), ERW ASTM A513 Type 1, 3 ft length. Barrel takes 600 mm; the remaining ~308 mm stays as stock. | McMaster 6045N87 | tubo redondo 3" ced. 10 (equivalente) | $42.13 | $42.13 |
| Drive shaft stock | 1 | 35 mm cold-rolled round rod x 1 m (1045 preferred). The shaft is 756 mm, so ~244 mm is left over. | McMaster -- SAME ORDER as the barrel | barra de acero estirado en frio 35 mm | $68 | $68 |
| Drill bushings, type P (press-fit, headless) | 1 | set for the printed jigs: 6 / 6.4 / 11 / 12 mm ID. **Not yet modelled:** the jigs as drawn bore for the BIT (hole + `print_clearance`), not for a bushing OD. Seating these is a jig change -- see the note under this table. | McMaster -- SAME ORDER as the barrel | bujes de broca tipo P | $44 | $44 |
| D6-3 rotor + stator set | 1 | stator 89 OD x 270, 73 ShA, 3 mm max grain | German pump supplier (owner-sourced) | same | $320 | $320 |
| Paddle drill (PRIMARY DRIVE) | 1 | 900 W spade-handle, 1/2" chuck, low range 0-550 rpm, variable trigger | owner already has | owner already has | $0 | $0 |
| Pillow blocks | 2 | UCP207, 35 mm bore, cast, set-screw | any import UCP207 | chumacera de piso UCP207 | $17 | $34 |
| Hardware cloth | 1 | 1/8" (3.2 mm) galvanised, 350 x 350 -- the sand sieve | hardware store | malla mosquitero/gallinero 1/8" | $12 | $12 |
| Printed-part hardware | 1 | M8 x 40 x 8 + nuts/washers (drill cradle), M6 x 60 x 8 (jigs), M4 x 20 x 8 (sand screen), 8 x 300 mm nylon straps or 4 x 100 mm hose clamps | hardware store | ferreteria | $26 | $26 |
| Ball valve, discharge | 1 | 1" NPT full port, lever, steel or brass | owner already has | owner already has | $0 | $0 |
| Ball valve, bypass | 1 | 1" NPT full port -- the relief path, see README | hardware store | ferreteria | $19 | $19 |
| Pressure gauge | 1 | 0-16 bar (0-230 psi) glycerin-filled, 1/4" NPT bottom | Winters PFQ / Grainger | manometro glicerina 0-16 bar | $26 | $26 |
| Gauge isolator | 1 | 1/4" NPT diaphragm gauge saver, grease-filled | McMaster 4045K | sello diafragma 1/4" | $24 | $24 |
| Grout hose | 1 | 1" ID x 8 m concrete placement hose, >= 40 bar WP, crimped ends | Gates / JGB | manguera para concreto 1" | $130 | $130 |
| Whip checks | 2 | hose-to-hose safety cable, 1" hose | Dixon WS2 | cable de seguridad para manguera | $9 | $18 |
| Half coupling, discharge | 1 | 1" NPT 3000# forged steel | hardware store | media copla 1" cedula 80 | $8 | $8 |
| Half couplings, POST PORTS | 12 | 1" NPT 3000# forged steel, one per post. Welds to a FLAT face of the square PTR -- no saddle cut, no fish-mouth. | hardware store | media copla 1" cedula 80 | $8 | $96 |
| Half coupling, gauge | 1 | 1/4" NPT 3000# forged steel | hardware store | media copla 1/4" | $4 | $4 |
| Half coupling, grease | 1 | 1/8" NPT 3000# forged steel | hardware store | media copla 1/8" | $4 | $4 |
| Grease nipple | 1 | 1/8" NPT straight zerk | hardware store | grasera 1/8" | $3 | $3 |
| Gland packing | 1 | square graphite/PTFE packing, 1 m coil. **The box wants 10 mm** ((gland_box_id 62.7 - sleeve_od 42.2)/2 = 10.25 mm of annulus). The 1/4" (6.35 mm) coil on the McMaster order is **3.9 mm short of filling it** -- see the note under this table before it goes in. | McMaster -- SAME ORDER as the barrel | empaquetadura de grafito 10 mm | $26 | $26 |
| Threaded rod | 1 | M10 x 1 m, class 8.8 (or 3/8-16 grade 5) | hardware store | varilla roscada M10 grado 8.8 | $9 | $9 |
| Nuts + washers | 1 | M10: 16 nyloc + 16 flat, 8.8 | hardware store | ferreteria | $11 | $11 |
| Dowel pins, joint | 2 | 12 mm x 60 hardened dowel, ground | McMaster 98381A | perno endurecido 12 mm | $7 | $14 |
| Roll pins, auger | 6 | 6 x 45 spring/roll pin | hardware store | pasador elastico 6 x 45 | $1 | $6 |
| Fastener kit | 1 | M12 x 8 (pillow blocks), M10 x 12 (flange/gland), M8 x 8, M6 x 6, all with nuts + washers | hardware store | ferreteria | $38 | $38 |
| Nitrile sheet | 1 | 3 mm x 300 x 300, 60-70 Shore A (stator + flange gaskets) | McMaster 8635K | hule nitrilo 3 mm | $16 | $16 |
| Electrical kit | 1 | IP55 enclosure, on/off with thermal overload set 1.15 x FLA, 20 A breaker, 30 mA RCD, 2.5 mm2 cable, plug | hardware store | arrancador con relevador termico | $98 | $98 |
| Filament | 1 | see out/print_manifest.md for the exact split and totals. ASA for anything that lives outdoors or against a warm drill; PETG for the rest. | any | any | $155 | $155 |
| Paint | 1 | etch primer + enamel | hardware store | ferreteria | $26 | $26 |
| Anti-seize + grease | 1 | copper anti-seize for the tie rods; EP2 for the gland | hardware store | ferreteria | $18 | $18 |
| | | | | | **TOTAL** | **$1,295.13** |

Without the rotor/stator set (owner already bought it): **$975.13**.

> **One McMaster order, placed.**  The barrel is the first part to arrive (Monday).  Its
> **$42.13** is the only invoice figure in the table above; everything else is still an
> estimate.  On the same order: the 35 mm cold-rolled shaft rod, the press-fit
> type-P drill bushings, and the square graphite gland packing.  Two of those three
> need a decision before they are used:
>
> - **Packing size.**  The box annulus is 10.25 mm, so `packing_sq` is 10 mm.  A 1/4"
>   (6.35 mm) coil leaves ~3.9 mm of the annulus unfilled: the rings roll instead of
>   squaring up, and they extrude past the follower on the first pressure stroke.
>   The nearest McMaster size that works is **3/8" (9.53 mm)**.  Nothing in the CAD
>   changed for this -- `packing_sq` is still 10 mm and the gland plate, follower and
>   box are cut for it.  Check the coil before it goes in.
> - **Bushings.**  The printed jigs bore for the BIT, not for a bushing OD, so a
>   type-P bushing has nothing to press into today.  Seating them means printing the
>   jig holes at the bushing OD with an interference, which is a jig change this
>   revision has not made.  Until then the bushings are stock, and the jigs guide
>   the bit in plastic exactly as coupon `B` measures them.

> **Two different 3" stocks, and only one of them is settled.**  The pump barrel is ROUND
> tube (76.2 OD x 3.05), **CONFIRMED** -- McMaster 6045N87, purchased and certified.
> The twelve posts are SQUARE PTR (76.2 across flats x 3.05) and are **still TBD**:
> separate purchase, separate `params.py` block, no cross-reference either way.  Measure
> the posts; do not carry the barrel's certificate across to them.  The square bore holds
> 29.5 L per post, 27% more than round tube of the same nominal size, and the
> cement order follows from it.

## 2. Fabricated -- steel

Every DXF named here is in `out/`.  Cut lengths are square cuts unless stated.

| Item | Qty | Stock | Cut / operations |
|---|--:|---|---|
| Barrel (ROUND tube -- not post stock) | 1 | McMaster 6045N87, 3 ft x 76.2 OD x 3.05 wall (CONFIRMED) | cut 600 mm from the 914 mm length, square both ends. Slot 200 x 50 in the top (developed width 54.5 -- use barrel_slot_wrap_template.dxf), **clocked away from the ERW seam** -- see the note below. |
| Adapter plate | 1 | 10 mm plate | 135 x 135; bore 50; 4 x 11 on 125.7 BC (diagonals). adapter_plate.dxf |
| Discharge rear plate | 1 | 10 mm plate | 135 x 135; bore 54; same 4 tie holes. discharge_rear_plate.dxf |
| Discharge chamber ring | 1 | 2" sch40 pipe | 2" sch40 (60.3 OD x 52.5 ID) x 35 mm |
| Discharge cap | 1 | 10 mm plate | 90 x 90; bore 27. discharge_cap.dxf |
| Tie-rod spacers | 4 | 3/4" sch40 pipe | 3/4" sch40 (26.7 OD x 20.9 ID) x 268 mm x4  <-- CUT ALL FOUR TOGETHER, +/-0.2 mm. These are the hard stop. |
| Tie rods | 4 | M10 rod 8.8 | cut 328 mm each |
| Barrel rear flange | 1 | 10 mm plate | 140 sq; bore 70.1; 4 x 11 on 118 BC. barrel_rear_flange.dxf |
| Barrel rear cover | 1 | 10 mm plate | 140 sq; bore 73 (2-7/8" hole saw); same bolt pattern + 2 x M10 gland studs at 96 centres. barrel_rear_cover.dxf |
| Stuffing box | 1 | 2-1/2" sch40 pipe | 2-1/2" sch40 (73.0 OD x 62.7 ID) x 95 mm; 8 mm grease hole at 26 mm from the inner end |
| Shaft sleeve (sacrificial) | 2 | 1-1/4" sch40 pipe | 1-1/4" sch40 (42.2 OD x 35.0 ID) x 110 mm x2  <-- make two; it is a consumable |
| Gland plate | 1 | 12 mm plate | 136 x 60; bore 44; 2 x 11 at 96. gland_plate.dxf |
| Gland studs | 2 | M10 rod | cut 90 mm, weld into the rear cover |
| Drive shaft | 1 | 35 mm cold-rolled bar (1045 preferred) | cut 756 mm; 2 x 6 cross holes at 148 pitch (use the printed jig); 1 x 8 mm cross hole at the rear for the drill stub; 10 x 8 keyway at the coupling (file it, or buy a keyed shaft) |
| Shaft tongue | 1 | 12 mm flat bar | 32 wide x 70 long; 12.5 pin hole. Slot the shaft nose 12 mm wide x 55 deep, insert, fillet both sides. shaft_tongue.dxf |
| Con-rod bar | 1 | 32 mm round bar | cut 91 mm |
| Con-rod ears | 4 | 8 mm plate | 32 x 45; 12.5 pin hole 14 from the end. THE TWO FORKS ARE AT 90 DEG TO EACH OTHER -- see cad/conrod.py |
| Hex stub -- PRIMARY INPUT | 1 | 1-1/4" sch40 pipe + 1/2" A/F hex bar | 60 mm pipe + 70 mm hex free length, plug-welded; 8 mm cross hole. The drill chucks straight onto this. |
| Drill torque lug | 1 | 10 mm plate | 90 x 70, half-round R21.5 to the MEASURED aux-handle collar; welded to the upright. THE ONLY TORQUE PATH. |
| Drill cradle plate | 1 | 10 mm plate | 46 x 180; 4 x M8 tapped or clearance for the printed saddle |
| Break-in spacer set | 4 | 3/4" sch40 pipe | cut 269.5 mm x4 -- 0.5 mm crush instead of 2.0. Gauge them on the printed tie-rod gauge. This set is the first thing to try if the drill will not carry the stator friction. |
| Hopper walls | 2 | 3 mm sheet | trapezoid 520/210 x 492 slant, +20 lap. hopper_wall_long_x2.dxf |
| Hopper walls | 2 | 3 mm sheet | trapezoid 420/70 x 485 slant. hopper_wall_short_x2.dxf |
| Hopper rim | 1 | 1" x 1/8" flat bar | ~1.9 m, welded round the top edge |
| Throat collar sides | 2 | 3 mm sheet | 210 x 60. hopper_collar_side_x2.dxf |
| Throat collar ends | 2 | 3 mm sheet | 70 x 60 with an R38.1 saddle cut. hopper_collar_end_x2.dxf |
| Grate | 1 | 3 mm sheet + 6 mm bar | frame 580 x 480, bars at 25 pitch. TRAMP GUARD, NOT A SIEVE -- see README. hopper_grate.dxf |
| Barrel saddles | 2 | 6 mm plate | 120 x 80 with an R38.1 notch |
| Pillow-block sub-plate | 1 | 10 mm plate | 260 x 160; 4 x 14 x 40 slots along x so the drive train withdraws |
| Lifting eyes | 4 | 12 mm plate | 80 x 60 with a 30 mm hole |
| Frame | 1 | PTR 51 x 51 x 3.05 | see out/frame_weldment.svg for the full cut list (~19 m) |

> **Fab note -- the barrel's ERW seam.**  6045N87 is ERW (electric resistance welded)
> ASTM A513 Type 1, so there is a weld-seam ridge running the full length of the bore.
> It is typically a few tenths of a millimetre proud, occasionally up to ~0.5 mm.
>
> **It is harmless here.**  The auger runs at 4.0 mm radial clearance (auger OD 62
> in a 70.1 bore); a 0.5 mm ridge spends one eighth of that.  Do not bore, hone or
> ream the barrel to chase it -- the wall is only 3.05 mm and it is a pressure boundary.
>
> Two things to do instead, in order:
>
> 1. **Clock the hopper slot away from the seam.**  Free, and it is the whole fix.
>    Find the seam before you mark out (see README section 2a), then put the
>    200 x 50 slot on the opposite side of the tube.  The slot is where grout enters
>    and where the flights are least supported; a ridge under the throat is the one
>    place it could pack material.  Anywhere else it is just a rib in a 70.1 bore.
> 2. **Optional:** with the slot cut, a flap wheel on an extension will reach most of
>    the seam through the opening.  Knock the ridge down, do not try to remove it.
>    Five minutes; skip it if the auger turns freely by hand on assembly.

### Plate nesting

- 10 mm plate: adapter plate + discharge rear plate + discharge cap + sub-plate fit inside one **350 x 350** offcut.
- 12 mm plate: gland plate + shaft tongue + lifting eyes, one **250 x 200** offcut.
- 3 mm sheet: the hopper develops into four flat trapezoids; nest them head-to-tail inside **1200 x 900**.

## 3. Printed

The full print list -- 29 models, 53 parts, material, walls, infill, print
orientation and consumable-vs-one-time-jig -- is generated into
**`out/print_manifest.md`**.  It is not duplicated here, because a BOM and a
manifest that disagree are worse than either alone.

Summary: about 6.7 kg of filament across 53 parts, in three groups --

- **WETTED** augers, gland follower, lantern ring, stator cradle and strap;
- **FAB JIGS** barrel and post drill saddles, 1:1 flange templates, PTR tack
  fixtures (sacrificial), tie-rod spacer gauge -- none of these is on the
  finished machine;
- **OPERATIONAL** drill cradle, hopper guard tiles, sand screen, funnel, twelve
  port dust caps, packing tools.

**Rule:** printed parts guide, feed, align, screen, cover and assist the seal.
They never contain pressure and never carry structural load.  The jigs never
stay in the pressure path, and the two PTR weld fixtures are sacrificial.

## 3b. NOT PURCHASED -- motor upgrade path

Deleted from the BOM above and **excluded from the total**.  Kept here because
the machine is built to accept it without modification: the motor + reducer
drive the SAME hex stub through a coupling half bored to 12.7 A/F, and nothing
on the pump changes.  Fit it if the measured stator friction turns out to be
more than the drill can carry -- `calcs/pump_calcs.py` section 4 prints the
break-even number.

| Item | Spec | Est. |
|---|---|--:|
| 1-phase motor | 1.5 kW 220 V 4-pole, frame 90L, B14 FT130, 24 mm shaft | $210 |
| Worm reducer | NMRV-050 7.5:1, 90B14 input, 25 mm output | $135 |
| Jaw coupling | L-110 / ROTEX-38, one half bored 12.7 A/F hex, one 25 mm | $48 |
| Motor outrigger + shelf | ~1.2 m more PTR, plus the brace | $12 |
| Electrical kit | IP55 starter with overload at 1.15 x FLA, 20 A, 30 mA RCD | $98 |
| | **UPGRADE TOTAL (not in the BOM)** | **$503** |

Note the frame drawing has no motor mount.  Adding one is a 1.2 m outrigger
welded to the left skid rail -- the worm input sits at 90 degrees to its output,
so the motor lies crosswise.

## 4. Consumables to stock before the pour

| Item | Qty |
|---|--:|
| Auger segments (a set is a wear item) | 1 spare set |
| Shaft sleeve, 1-1/4" sch40 x 130 | 1 spare |
| Gland packing | 1 m spare |
| Gland follower + lantern ring | 2 spare each |
| 3 mm nitrile gaskets | 4 spare |
| Printed auger set | 1 spare set (see print manifest) |
| Cement -- 12 x square posts, 29.5 L each | 236 kg = 4.7 sacks of 50 kg |
| Sand, sieved <= 3 mm through the printed screen | ~472 kg |
| Water | ~118 L, plus 200 L for flushing |

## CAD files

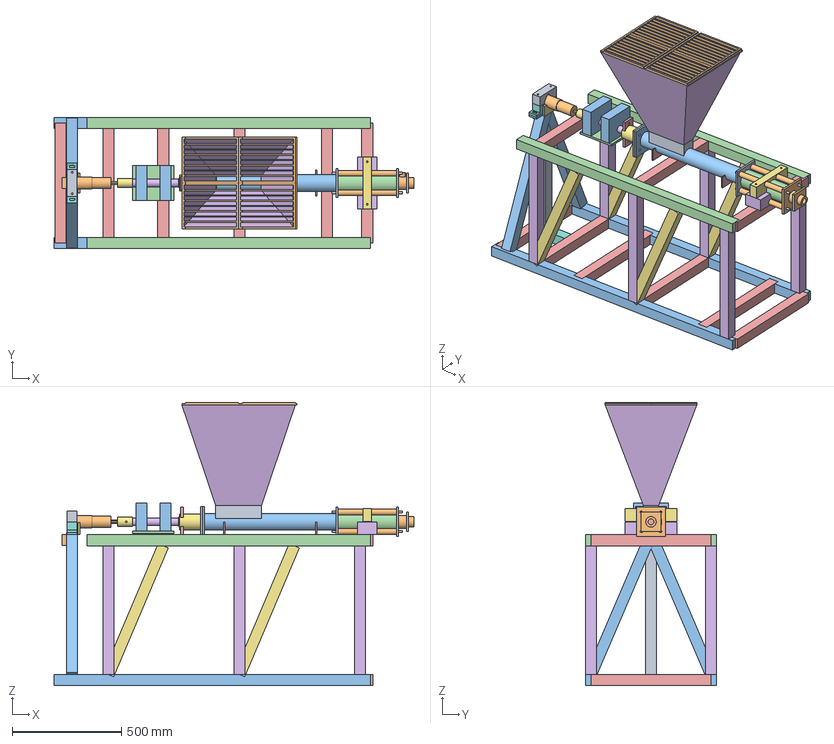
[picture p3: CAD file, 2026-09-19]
out/machine_assembly.step
1648.0 x 600.0 x 1297.0 mm
adapter_plate
discharge_head
barrel_rear_flange
barrel_rear_cover
gland_plate
drive_shaft
hex_stub
conrod
shaft_tongue
auger_segment_1
auger_segment_2
auger_scavenger
gland_follower
lantern_ring
stator_cradle
stator_strap
drill_cradle_saddle
drill_cradle_strap
hopper_guard_tile_FL
hopper_guard_tile_FR
hopper_guard_tile_RL
hopper_guard_tile_RR
barrel_tube_ENV
stator_ENV
rotor_ENV
shaft_sleeve_ENV
stuffing_box_ENV
packing_ring_1_ENV
packing_ring_2_ENV
packing_ring_3_ENV
packing_ring_4_ENV
tie_rod_1_ENV
tie_spacer_1_ENV
tie_rod_2_ENV
tie_spacer_2_ENV
tie_rod_3_ENV
tie_spacer_3_ENV
tie_rod_4_ENV
tie_spacer_4_ENV
pillow_block_front_ENV
pillow_block_rear_ENV
pb_subplate_ENV
barrel_saddle_1_ENV
barrel_saddle_2_ENV
hopper_ENV
drill_torque_lug_ENV
drill_cradle_plate_ENV
throat_collar_ENV
DRILL_ENV
frame_01_skid_rail_ENV
frame_02_top_rail_ENV
frame_03_skid_rail_ENV
frame_04_top_rail_ENV
frame_05_skid_cross_ENV
frame_06_skid_cross_ENV
frame_07_skid_cross_ENV
frame_08_skid_cross_ENV
frame_09_skid_cross_ENV
frame_10_skid_cross_ENV
frame_11_top_cross_ENV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

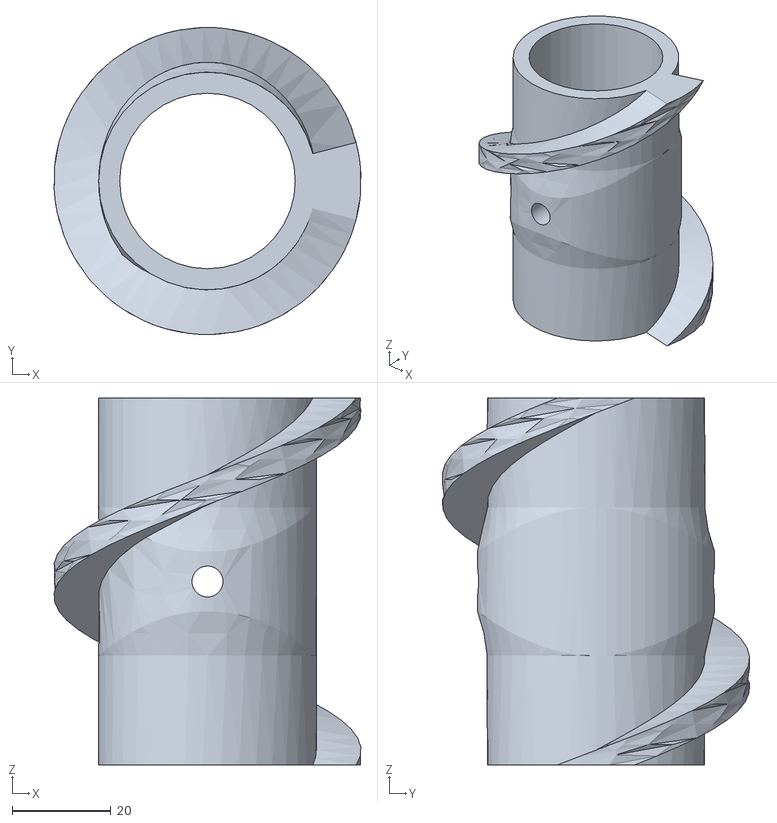
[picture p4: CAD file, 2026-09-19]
out/auger_scavenger_p74_L74.stl
62.0 x 62.1 x 74.2

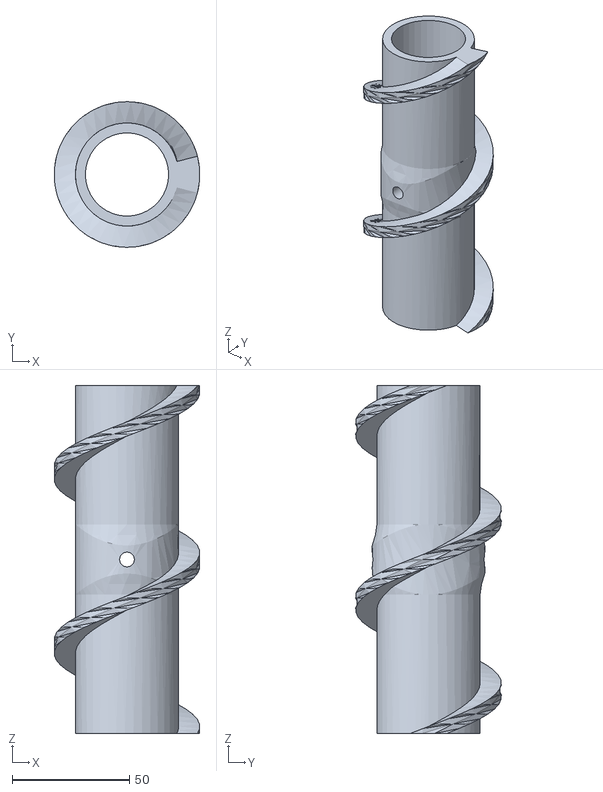
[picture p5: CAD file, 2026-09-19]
out/auger_segment_p74.stl
62.0 x 62.1 x 148.4

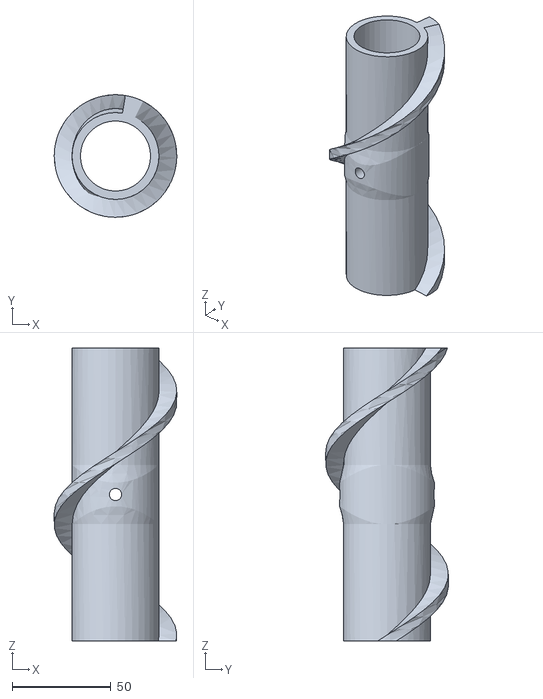
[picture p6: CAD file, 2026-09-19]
out/auger_segment_p124_SPARE.stl
62.1 x 62.1 x 148.4

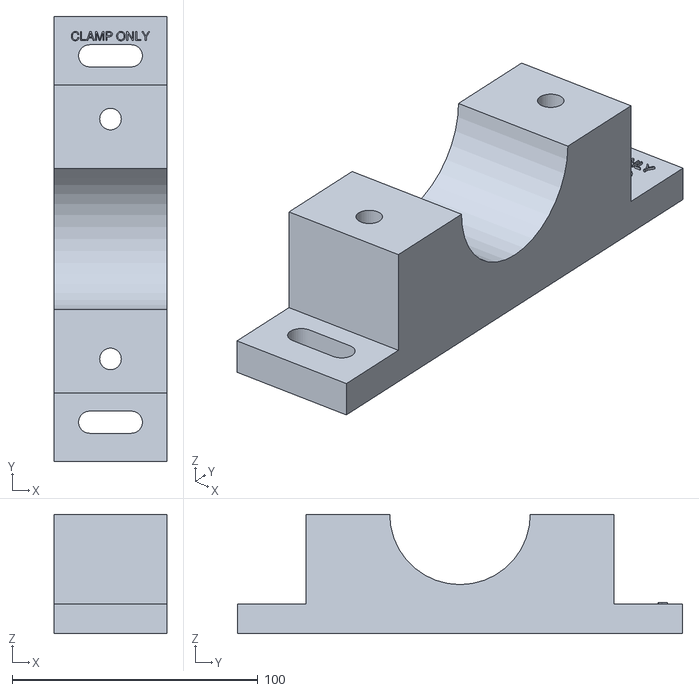
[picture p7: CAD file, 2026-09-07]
out/drill_cradle_saddle.stl
46.0 x 181.2 x 48.6

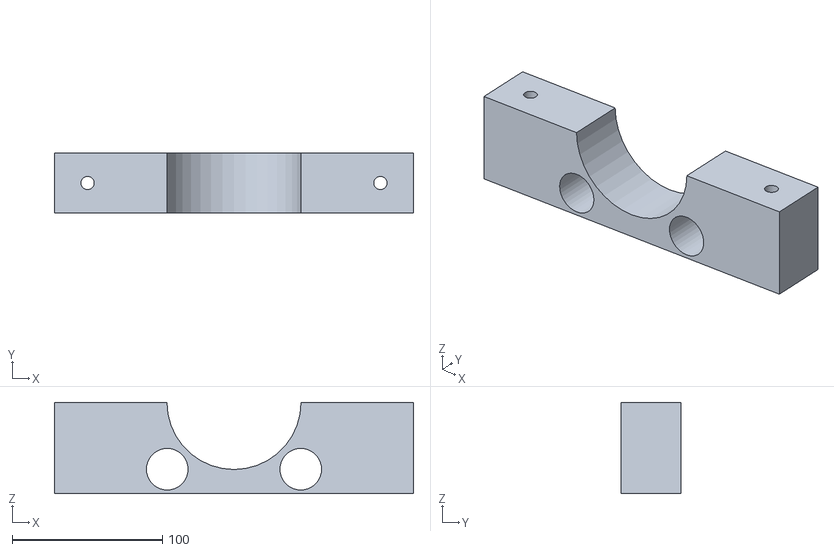
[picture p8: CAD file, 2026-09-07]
out/stator_strap.stl
239.0 x 40.0 x 60.6

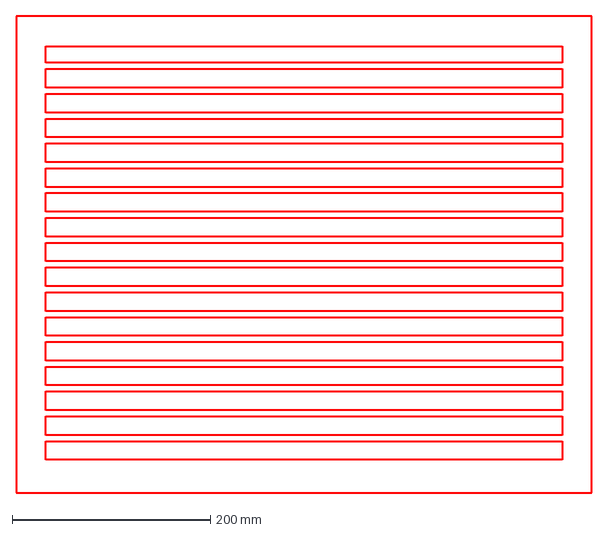
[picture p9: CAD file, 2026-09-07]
out/hopper_grate.dxf
580.0 x 480.0 mm

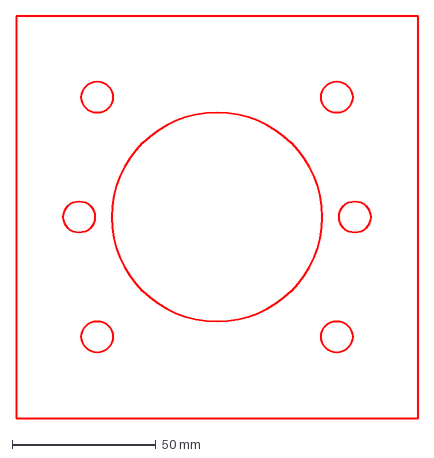
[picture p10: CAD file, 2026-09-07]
out/barrel_rear_cover.dxf
140.0 x 140.0 mm

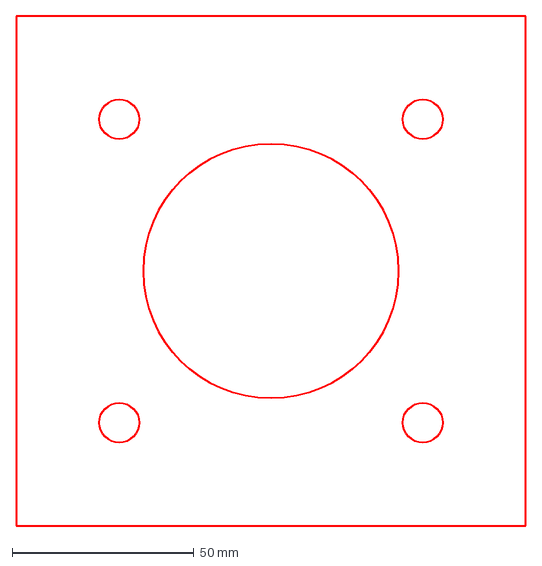
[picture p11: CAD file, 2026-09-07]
out/barrel_rear_flange.dxf
140.0 x 140.0 mm

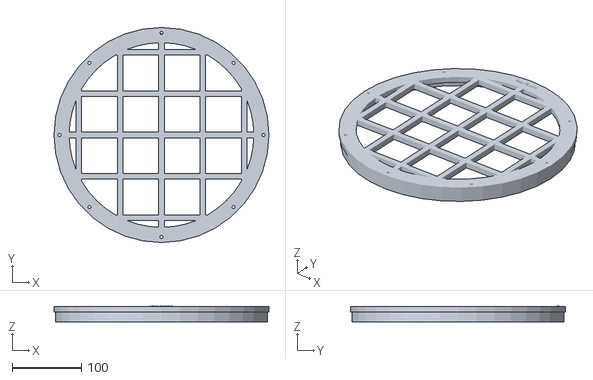
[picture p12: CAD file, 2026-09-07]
out/sand_screen_frame.stl
311.0 x 311.0 x 22.8

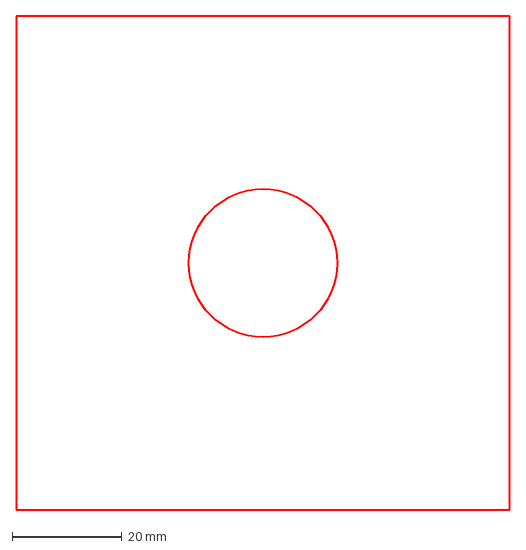
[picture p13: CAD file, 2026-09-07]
out/discharge_cap.dxf
90.0 x 90.0 mm

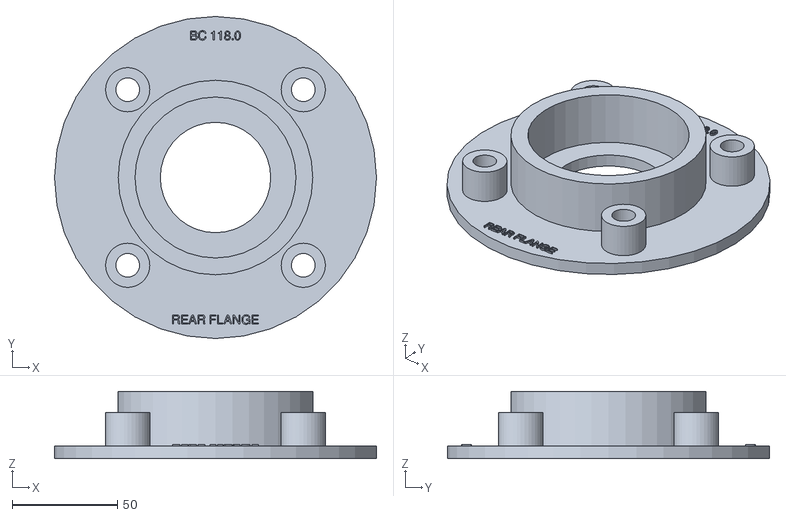
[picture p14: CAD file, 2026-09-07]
out/jig_barrel_rear_flange.stl
153.0 x 153.0 x 32.0

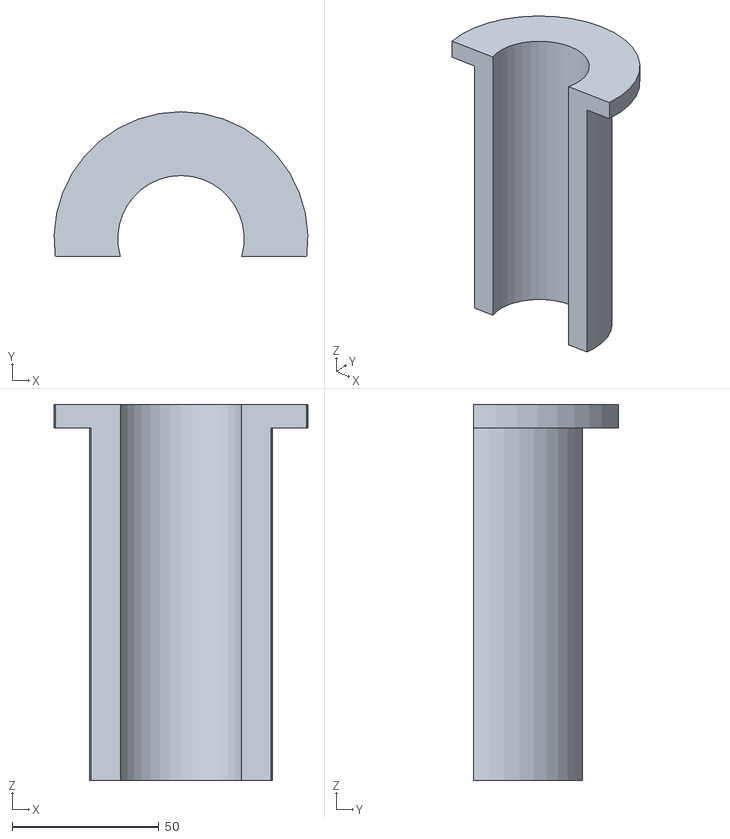
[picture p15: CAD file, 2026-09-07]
out/packing_drift.stl
86.4 x 49.2 x 128.0

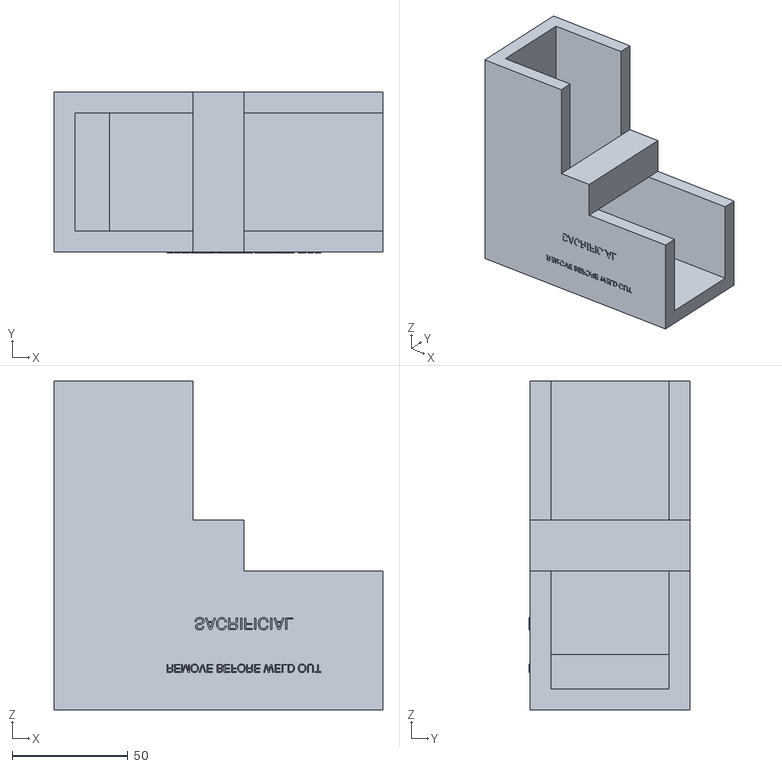
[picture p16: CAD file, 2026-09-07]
out/fixture_ptr_corner_SACRIFICIAL.stl
142.0 x 69.5 x 142.0

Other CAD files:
out/joint_boot_clamp.stl
out/template_barrel_rear_flange.stl
out/fixture_ptr_tee_SACRIFICIAL.stl
out/template_discharge_flange.stl
out/adapter_plate.dxf
out/adapter_plate.step
out/barrel_slot_wrap_template.dxf
out/conrod.step
out/discharge_head.step
out/discharge_rear_plate.dxf
out/drill_cradle_strap.stl
out/drive_shaft.step
out/fit_coupons.stl
out/gauge_tie_rod_spacers.stl
out/gland_follower.stl
out/gland_plate.dxf
out/hex_stub_PRIMARY_INPUT.step
out/hopper_collar_end_x2.dxf
out/hopper_collar_side_x2.dxf
out/hopper_funnel.stl
out/hopper_guard_tile.stl
out/hopper_wall_long_x2.dxf
out/hopper_wall_short_x2.dxf
out/jig_barrel_hopper_slot.stl
out/jig_barrel_tie_rods.stl
out/jig_post_port.stl
out/jig_post_vent.stl
out/lantern_ring.stl
out/npt_dust_cap.stl
out/packing_cone.stl
out/sand_screen_retainer.stl
out/shaft_tongue.dxf
out/stator_cradle.stl
out/template_adapter_plate.stl

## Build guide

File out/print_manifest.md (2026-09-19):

# PRINT MANIFEST -- TUBE-FILLER

<!-- GENERATED by cad/manifest.py.  Do not edit: run `python cad/build_all.py`. -->

Bambu H2C, 0.4 mm nozzle, 0.2 mm layers.  **No supports on any part** -- every
model is emitted in its print orientation and every overhang is at 45 degrees
or steeper.  Where a part is listed as ASA, the reason is UV and heat: it lives
outdoors or against a warm drill.  Everything else is PETG.

Bed checked against 350 x 320 x 325 mm (`printer_x/y/z` in params.py -- confirm against your machine).

## Fit tuning -- do this before you batch anything

Every printed feature that has to fit real steel is derived from **one**
number, so one measurement retunes the whole project:

| parameter | now | governs |
|---|--:|---|
| `print_clearance` | 0.25 mm | DIAMETRAL clearance of a printed feature over real stock: auger cross-pin holes, jig register faces on the tube and on the square post, drill bushings on the bit, cradle on the stator, drill saddle on the drill body, gland follower in its box, PTR weld fixtures. Applied as half of it where the feature is a face or a radius. |
| `print_interference` | 0.50 mm | DIAMETRAL *oversize* of a printed barb that must grip -- the NPT dust caps, and nothing else. Tuned in the opposite direction. |
| `running_clearance` | 0.80 mm | NOT a fit: the gap in a printed bore around something that turns in it (gland follower and lantern ring on the rotating shaft sleeve). Do not tune this from a coupon. |
| `auger_bore_clear` | 0.50 mm | NOT a fit either: the auger hub bore over the 35 mm shaft, fixed at a loose slide. The 6 mm cross pin locates the segment and carries the drive, so the bore only has to go on and come off a wet, gritty shaft with five segments to line up. Deliberately decoupled from `print_clearance`. |

`fit_coupons.stl` is a ladder of five rungs either side of each, 0.10 mm apart, every rung embossed with its own value:

| tag | coupon | test it on | looking for |
|---|---|---|---|
| `A` | auger **cross-pin hole**, in a hub ring on the shaft | the real 35 mm shaft and a 6 mm pin | pin pushes through by hand, no slop. The ring's own bore steps too, but the auger's bore is a fixed 0.50 mm slide and is not read from here. |
| `P` | post-jig corner channel | a real 76.2 square PTR corner | both faces touch, no rock, comes off by hand |
| `B` | template drill bushing | the real 11 mm bit | spins freely, no perceptible wobble. **This is the tightest use in the project** -- if one rung is snug here and loose elsewhere, this is the rung that decides. |
| `C` | dust-cap barb | a real 1" NPT half coupling | firm thumb to seat, stays put upside down |

> **Mesh tolerance is part of the fit.** Every STL here is meshed at `stl_tolerance` = 0.02 mm chordal, which makes a bore an
> inscribed polygon up to 0.04 mm small on diameter. That cancels -- coupons and parts
> mesh identically, so a coupon measures the faceting along with everything else --
> but only while the number is the same for both. **Changing `stl_tolerance` invalidates a
> measured `print_clearance`.** Re-run the coupons if you touch it.

Each coupon is modelled in the same print orientation as the part it stands
for -- the auger bore vertical, the corner channel on its 45-degree corner, the
bushing flat. A fit measured in one orientation does not transfer to another.

Then: **edit two numbers, re-run the build, and batch.**

> **The rule, unchanged:** printed parts GUIDE, FEED, ALIGN, SCREEN, COVER and
> SEAL-ASSIST.  None of them contains pressure or carries structural load.  The
> fab jigs are shop tools: none of them stays in the pressure path, and the two
> PTR weld fixtures are sacrificial and must be off the work before weld-out.

## FIT COUPON

One plate, printed and tested BEFORE anything else. See the fit-tuning section above.

| STL | Qty | Mat | Walls | Infill | Orientation | Life | Solid cm3 | Est. g ea |
|---|--:|---|--:|--:|---|---|--:|--:|
| `fit_coupons.stl` | 1 | PETG | 3 | 30% | as laid out -- each coupon is already in its parent part's orientation | print first, then discard | 257 | 215 |

- **fit_coupons** -- 20 coupons on one plate: 5 rungs each of the auger bore, the post corner channel, a template drill bushing and the dust-cap barb. Try every rung on real stock, then set print_clearance.

## WETTED

On the machine, in contact with grout. Existing parts, unchanged by the drill conversion.

| STL | Qty | Mat | Walls | Infill | Orientation | Life | Solid cm3 | Est. g ea |
|---|--:|---|--:|--:|---|---|--:|--:|
| `auger_segment_p74.stl` | 2 | PETG | 4 | 100% | axis vertical, flat face down | consumable | 100 | 126 |
| `auger_scavenger_p74_L74.stl` | 1 | PETG | 4 | 100% | axis vertical | consumable | 51 | 65 |
| `auger_segment_p124_SPARE.stl` | 2 | PETG | 4 | 100% | axis vertical | spare | 92 | 117 |
| `gland_follower.stl` | 3 | PETG | 4 | 100% | shoulder down | consumable | 45 | 58 |
| `lantern_ring.stl` | 3 | PETG | 4 | 100% | flat | consumable | 16 | 20 |
| `stator_cradle.stl` | 1 | ASA | 4 | 40% | saddle up, flat base down | permanent | 854 | 473 |
| `stator_strap.stl` | 1 | ASA | 4 | 40% | arch up as modelled | permanent | 399 | 232 |
| `joint_boot_clamp.stl` | 2 | PETG | 3 | 40% | flat | permanent | 8 | 9 |

- **auger_segment_p74** -- flight self-supports: 97% layer overlap. No supports. Pin boss is a faired lens, 48 swept x 30 -- print it as modelled, do not thicken it: calcs 5b gates the feed on that diameter.
- **auger_scavenger_p74_L74** -- sweeps the annulus in front of the gland
- **auger_segment_p124_SPARE** -- coarser pitch. Print only if the primary auger starves.
- **gland_follower** -- compression only, fully supported in the bore
- **lantern_ring** -- grease distribution; not a seal
- **stator_cradle** -- non-structural alignment only
- **stator_strap** -- finger tight only
- **joint_boot_clamp** -- retains an inner-tube boot over the pin joint

## FAB JIG

One-time shop tools. None of these is on the finished machine.

| STL | Qty | Mat | Walls | Infill | Orientation | Life | Solid cm3 | Est. g ea |
|---|--:|---|--:|--:|---|---|--:|--:|
| `jig_barrel_hopper_slot.stl` | 1 | PETG | 3 | 15% | vee mouth down, as modelled | one-time jig | 1969 | 651 |
| `jig_barrel_rear_flange.stl` | 1 | PETG | 3 | 20% | flat disc down | one-time jig | 166 | 115 |
| `jig_barrel_tie_rods.stl` | 1 | PETG | 3 | 20% | flat disc down | one-time jig | 177 | 123 |
| `jig_post_port.stl` | 1 | PETG | 3 | 15% | outer corner down, both legs at 45 deg | one-time jig | 440 | 193 |
| `jig_post_vent.stl` | 1 | PETG | 3 | 15% | outer corner down, both legs at 45 deg | one-time jig | 350 | 155 |
| `template_adapter_plate.stl` | 1 | PETG | 3 | 20% | flat, bushings up | one-time jig | 78 | 73 |
| `template_discharge_flange.stl` | 1 | PETG | 3 | 20% | flat, bushings up | one-time jig | 77 | 73 |
| `template_barrel_rear_flange.stl` | 1 | PETG | 3 | 20% | flat, bushings up | one-time jig | 78 | 74 |
| `fixture_ptr_corner_SACRIFICIAL.stl` | 2 | PETG | 3 | 20% | heel down as modelled | SACRIFICIAL | 413 | 224 |
| `fixture_ptr_tee_SACRIFICIAL.stl` | 2 | PETG | 3 | 20% | flat, pockets up | SACRIFICIAL | 336 | 192 |
| `gauge_tie_rod_spacers.stl` | 1 | PETG | 3 | 20% | flat | one-time jig | 350 | 210 |

- **jig_barrel_hopper_slot** -- strapped V-saddle. Chain-drill 6.4 through every bushing.
- **jig_barrel_rear_flange** -- registers on the barrel OD; bolt circle concentric with the tube
- **jig_barrel_tie_rods** -- same, for the adapter-plate tie-rod circle
- **jig_post_port** -- corner channel on two adjacent faces of the square PTR. Used 12 times. Foot butts the post BASE; port centred on the face at 150 mm.
- **jig_post_vent** -- corner channel on two adjacent faces of the square PTR. Used 12 times. Foot butts the post TOP; vent 100 mm down.
- **template_adapter_plate** -- 1:1. Outline is also the cut mark.
- **template_discharge_flange** -- 1:1
- **template_barrel_rear_flange** -- 1:1
- **fixture_ptr_corner_SACRIFICIAL** -- TACK ONLY. Remove before weld-out or you melt it into the joint.
- **fixture_ptr_tee_SACRIFICIAL** -- TACK ONLY. Remove before weld-out.
- **gauge_tie_rod_spacers** -- two lanes: SERVICE and BREAK-IN. All four spacers must gauge the same.

## OPERATIONAL

On the machine, not wetted.

| STL | Qty | Mat | Walls | Infill | Orientation | Life | Solid cm3 | Est. g ea |
|---|--:|---|--:|--:|---|---|--:|--:|
| `drill_cradle_saddle.stl` | 1 | ASA | 5 | 60% | foot down, cradle up | permanent | 241 | 188 |
| `drill_cradle_strap.stl` | 1 | ASA | 5 | 60% | as modelled, teardrop bore down | permanent | 217 | 167 |
| `hopper_guard_tile.stl` | 4 | ASA | 4 | 30% | flat | permanent | 216 | 194 |
| `sand_screen_frame.stl` | 1 | ASA | 4 | 30% | lip down | permanent | 335 | 280 |
| `sand_screen_retainer.stl` | 1 | ASA | 4 | 30% | flat | permanent | 119 | 103 |
| `hopper_funnel.stl` | 1 | ASA | 3 | 15% | small end down | permanent | 468 | 459 |
| `npt_dust_cap.stl` | 12 | PETG | 3 | 30% | flange down | consumable | 16 | 13 |
| `packing_cone.stl` | 1 | PETG | 4 | 40% | spigot down | permanent | 101 | 86 |
| `packing_drift.stl` | 2 | PETG | 4 | 60% | flange up, split face down | permanent | 131 | 127 |

- **drill_cradle_saddle** -- CLAMPING LOAD ONLY. Torque goes through the steel lug and upright.
- **drill_cradle_strap** -- line it with inner tube; you are clamping a plastic gearcase
- **hopper_guard_tile** -- drops into the welded steel rim; the STEEL bars carry the load
- **sand_screen_frame** -- 1/8in hardware cloth. THIS is the <=3 mm sieve.
- **sand_screen_retainer** -- 8 x M4 traps the cloth
- **hopper_funnel** -- walls lean ~14 deg from vertical; no supports
- **npt_dust_cap** -- debris cap, NOT a pressure cap
- **packing_cone** -- seats each ring square in the box
- **packing_drift** -- half-shell; two make a tube

## Totals

- **53 printed parts** in 29 distinct models.
- Estimated filament: **6.7 kg** (at the listed infills; 'Est. g' is density x perimeter shell volume plus infill fraction of the remainder -- a budgeting number, not a slicer).
- PETG **4.0 kg**, ASA **2.7 kg**.  Buy 5 kg and 4 kg: the auger set alone is a consumable you will reprint, and one
  of the sacrificial weld fixtures will get too close to an arc.
- Of that, **2.5 kg is one-time fab jigs** that do not stay on the machine.  That is the price of
  drilling 24 post holes and a hopper slot right the first time.

## Print order

0. **`fit_coupons` first, before anything else.** One plate, about an hour.
   Try every rung on the real shaft, the real PTR corner, the real drill bit
   and a real 1" coupling. Put the values that fit into `print_clearance` and
   `print_interference` in `params.py`, re-run `python cad/build_all.py`, and
   only then start batching. A wrong clearance found on part 40 of 53 is
   several kilos of filament and a weekend.
1. **Jigs first.** `jig_barrel_hopper_slot`, both `jig_barrel_*` rings and the
   three 1:1 templates, before you cut any steel. `gauge_tie_rod_spacers` before
   you cut the spacers -- that gauge is what stops you crushing the stator.
2. **PTR fixtures** before the frame day. Print 4 of each; they are sacrificial
   and one will get too close to an arc.
3. **Post jigs** before you touch the twelve posts. One print, 24 holes.
4. **Wetted parts** during the frame build: augers, gland follower, lantern ring,
   cradle, strap. Print the spare set at the same time.
5. **Operational parts** last: drill cradle, guard tiles, sand screen, funnel,
   dust caps, packing tools.

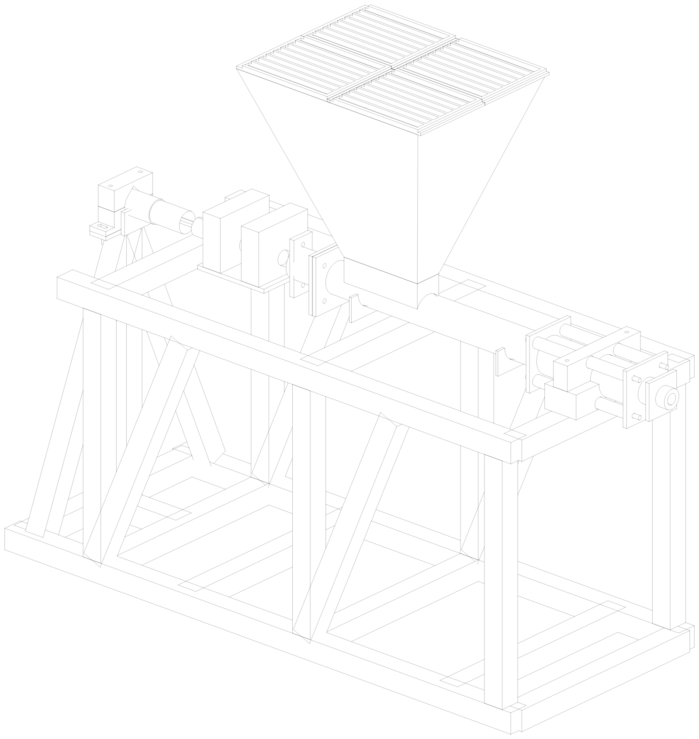
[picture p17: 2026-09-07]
out/assembly_iso.png

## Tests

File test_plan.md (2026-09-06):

# TUBE-FILLER — commissioning and test plan

Three stages, in order, no skipping: **water → cement milk → grout**. Each
stage has pass criteria you must meet before the next, and abort criteria that
stop the test immediately.

Nothing in stage 1 or 2 can hurt the stator. Stage 3 can. That is the whole
reason for the order.

**Kit for every stage:** clamp ammeter (true-RMS, 0–20 A), tachometer or a
phone slow-mo of a paint mark on the coupling, the 0–16 bar gauge already
fitted, a stopwatch, a 20 L graduated bucket, a wheelbarrow, two 17 mm
wrenches, a grease gun, PPE.

**Before any stage:** wet the stator, turn the pump two full revolutions by
hand at the coupling. If it will not turn by hand, stop — see abort A-1.

---

## Stage 0 — Dry checks (no fluid, no power)

| # | Check | Pass |
|---|---|---|
| D-1 | Turn the pump by hand at the hex stub, two revolutions | Turns with a firm but steady pull. No tight spot. |
| D-1b | **Measure the hand torque** with a torque wrench on the hex stub, slowly, one revolution | Record the peak. This is your first estimate of stator friction and it costs nothing. Over ~20 N.m: fit the break-in spacers before you go any further. |
| D-2 | Con-rod forks | The two pin axes are **90° apart**. Each joint rocks freely by hand in its own plane. |
| D-3 | Tie-rod spacers | All four within 0.2 mm of each other, and equal to `stator_len − stator_crush`. |
| D-4 | Tie-rod nuts | 20 N·m, even, in a cross pattern. Plates parallel within 0.5 mm across the diagonal. |
| D-5 | Shaft alignment | Straightedge across the coupling hubs, ≤ 0.2 mm step. |
| D-6 | Pillow-block collars | Both locked. Shaft will not move axially by hand. |
| D-7 | Auger clearance | Rotate the shaft one turn with the rear cover off; no rub anywhere in the barrel. |
| D-8 | Electrical | RCD trips on its test button. Overload set to 1.15 × FLA. Earth bonded to the frame, measured < 1 Ω. |
| D-9 | Gauge | Reads zero. Isolator diaphragm clean and screwed home. |
| D-10 | Guards | Coupling guard on. Grate bolted down. |

**Abort A-1:** the pump cannot be turned by hand → the spacers are too short
(over-crushed stator) or the rotor/stator pair is mismatched. Do not power it.
Re-cut the spacers 1 mm longer and retry.

---

## Stage W — Water test

Purpose: prove the drive, the gland, the bearings and the flow, and **measure
the stator friction torque** — the number the whole drive margin rests on.

Run first on the **drill stub** with a paddle mixer if the motor is not yet
fitted; then repeat on the motor.

| # | Step | Pass criteria |
|---|---|---|
| W-1 | Hopper full of clean water, discharge valve open, hose to the barrow. Start. | Pumps within 10 s. Steady stream, no large surging. |
| W-2 | Measure rotor speed | 185–200 rpm (design 193). Below 180 → check the ratio and the nameplate rpm. |
| W-3 | Measure flow: time filling the 20 L bucket | 8.5–10.5 L/min. Design 9.67. **Below 8 L/min on water = the stator is passing back; check crush and rotor fit.** |
| W-4 | **Measure the current, unloaded and running** | Record both. Compute the torque: `T_out = (I_run − I_noload)/(I_FLA − I_noload) × T_motor × ratio × 0.86`. Subtract the gland and auger allowances. **Put the result into `T_stator_friction` in `params.py` and re-run `calcs/pump_calcs.py`.** |
| W-5 | Gland | Weeps 1–3 drops per minute when running. Nip a flat at a time until it does. **A bone-dry gland is over-tight and will cook the sleeve.** |
| W-6 | Run 20 minutes continuously | Stuffing box warm, not hot — under 60 °C, i.e. you can hold your hand on it. Pillow blocks under 50 °C. Reducer under 70 °C. |
| W-7 | Deadhead test — **carefully** | With one hand on the bypass valve, slowly close the discharge valve while watching the gauge. **Stop at 6 bar and open the bypass.** Confirm: the machine reaches 6 bar with no leak at any joint, and the bypass drops it to zero in under 2 s. |
| W-8 | Leak check at 6 bar | No weep at either stator face, the adapter plate weld, the rear cover gasket, the chamber ring welds, or the gauge boss. |
| W-9 | Thrust | Shaft has not migrated. Mark it with a pen before and after. |

**Abort criteria — stop and fix before continuing:**
- **A-2** Running current above 1.15 × FLA → torque budget is wrong. Re-run the
  calcs with the measured friction; if the margin drops below 2.0, fit a 10:1
  reducer (and accept ~7.2 L/min) rather than pushing the motor.
- **A-3** Any leak at the stator faces at 6 bar → gaskets, or the plates are not
  parallel. Do not "just tighten it more" — the spacers stop you anyway, which
  is the point.
- **A-4** Stuffing box too hot to touch after 20 min → gland over-tight, or the
  sleeve is scored. Back off; if it persists, repack.
- **A-5** Gauge cannot reach 6 bar with the discharge shut → internal bypass in
  the stator. New stator or more crush (1 mm at a time).
- **A-6** Knocking, or flow that surges by more than ±20% → starving. Raise the
  hopper level; if it persists on water it will be far worse on grout.

**Only proceed when W-1 through W-9 all pass and `params.py` has the measured
friction torque in it.** If the drive verdict is anything but PASS, do stage B
first.

---

## Stage B -- Stator break-in  (only if W-4 came in over ~9 N.m)

Purpose: get the stator's interference torque down to something the drill can
carry, without touching anything else.

| # | Step | Pass criteria |
|---|---|---|
| B-1 | Fit the **break-in spacer set** (4 off, `stator_len - 0.5`, gauged on `gauge_tie_rod_spacers`). Nuts to 20 N.m. | All four spacers gauge identically. |
| B-2 | Re-measure hand torque at the stub (as D-1b) | Should already have dropped. |
| B-3 | Mix ~40 L of cement milk. Run 30 min, discharge open, recirculating into the barrow and back to the hopper. | Drill stays warm, not hot. Flow steady. |
| B-4 | Re-measure the friction (W-4) | Record. This is the number that decides the job. |
| B-5 | Swap to the **service spacer set**, re-measure | If the service set puts you back over the drill's continuous rating, **run the machine on the break-in set.** 0.5 mm of crush is ample for 3 bar and you can always go back. Note which set is fitted, in paint, on the frame. |
| B-6 | Flush completely (README section 8) before the milk sets | Nothing set anywhere. |

**Abort criteria:**
- **B-A1** Friction still over ~15 N.m after break-in on both spacer sets ->
  the drill is not going to drive this pump. Stop and fit the motor upgrade
  (README section 11). This is a real outcome, not a failure of the build; it
  is exactly why the hex stub was designed to take both.
- **B-A2** Flow falls below 10 L/min on the break-in spacers -> too little
  crush; the stator is slipping internally. Go back to the service set and
  accept the torque, or accept the lower flow and a longer fill.

---

## Stage M — Cement milk test

Cement and water only, **no sand**, roughly 1:1 by volume. About 40 L — one
hopper. Purpose: prove the machine against something that sets, at a viscosity
above water, without abrasive.

| # | Step | Pass criteria |
|---|---|---|
| M-1 | Prime and run into the barrow, discharge open | Flow within 8.0–10.5 L/min. |
| M-2 | Gauge, free discharge | 0.3–1.0 bar. |
| M-3 | Connect the full hose run and pump into the barrow through it | Gauge rises to 1–2 bar and holds steady. A *climbing* reading means the hose is packing. |
| M-4 | Drill load | No more than ~1 N.m (or ~1 A) above the water figure. Gearcase still only warm. |
| M-5 | Gland | Still weeping, still clean. Give it 2 strokes of grease and confirm clean grease appears at the follower. |
| M-5b | **Valve-before-trigger drill.** With the hose connected to a test tube, close the discharge valve, THEN release the trigger. Repeat five times. | It has to be automatic before there is grout in the machine. A drill freewheels: release first and the column drains back. |
| M-6 | Run the hopper down to the top of the barrel slot, then stop | Confirm you can see the level cue clearly from the operating position. This is the level you must never go below. |
| M-7 | **Full flush drill, timed** | Run README §8 steps 1–10 literally, with a stopwatch. Target: the stator and discharge head are off within **5 minutes** of the pump stopping. |
| M-8 | Inspect after the flush | Strip the drive train (§8 step 11). **No set material anywhere**: stator bore, adapter bore, barrel, auger flights, the annulus in front of the gland, the packing stack. |

**Abort criteria:**
- **A-7** M-8 finds set material in any cavity → the flush procedure is wrong for
  this build, not the operator. Find the cavity, fix the *machine* (or add the
  step), and repeat M-1 to M-8. **Do not go to grout with a cavity you cannot
  clean.** This is the single test that protects the stator.
- **A-8** Gauge climbing steadily at constant flow → hose is packing. Thin the
  mix or shorten the hose *now*, at zero cost, before there is sand in it.

---

## Stage G — Grout test

Full mix: 1:2 cement:sand, w/c ~0.50, sand **sieved to ≤ 3 mm at the pile**.
Mix one hopper (about 44 L, ~1.9 posts' worth).

Do this on a **13th post, or a length of offcut tube standing in the yard** —
not on one of the twelve. If it goes wrong you want the mistake in a scrap
tube.

| # | Step | Pass criteria |
|---|---|---|
| G-1 | Prime the hose with 5 L of cement milk first | Grout follows without a bridge. |
| G-2 | Pump into the barrow, free discharge | 8.5–10.5 L/min. Confirm against the bucket. |
| G-3 | Connect to the test post's 1" port. Pump. | Gauge settles in the **2–4 bar** band and stays there. |
| G-4 | Watch the vent at the top | Grout appears at the top in **2.0–3.0 min**. Stop when it does. |
| G-5 | Drill load | Within ~1.5 N.m of the water figure, and the gearcase still only warm after a full post. If it is hot after one post, plan a cooling break between posts and say so out loud to whoever is mixing. |
| G-6 | Compare the gauge to prediction | Compare to `calcs` section 3. If the real pressure is far above the τ₀=100 Pa row, set `grout_tau0` in `params.py` to match and re-run — you now know your actual mix. |
| G-7 | Flush, timed, per README §8 | Under 5 minutes to open. Nothing set at inspection. |
| G-8 | Next day: cut the test post open, or sound it | Solid fill, no voids, no segregation, no water pocket at the top. |

**Abort criteria:**
- **A-9** Gauge exceeds 6 bar → **open the bypass, stop.** Thin the mix, shorten
  the hose, or both. Never raise the pressure limit to suit the mix.
- **A-10** Flow drops while the current rises → the stator is packing or the
  auger is starving. Stop, open the bypass, flush immediately.
- **A-11** Grout appears at the gland → the packing has lost the fight. Stop,
  flush, repack, and increase the grease purge interval.
- **A-12** G-8 finds voids → the fill rate is too fast for the air to escape, or
  the vent is undersized. Slow down (a 10:1 reducer, or throttle at the
  discharge valve) and re-test. **Find this on the test post, not on post 9.**

---

## Production go/no-go

Go to the twelve posts only when:

- every Stage G criterion passed on the test post,
- `params.py` holds the **measured** `T_stator_friction` and `grout_tau0`,
- the drive verdict in `calcs` is PASS or MARGINAL, and if MARGINAL the day is
  planned around cooling breaks,
- which spacer set is fitted is painted on the frame,
- `python calcs/pump_calcs.py` still prints **all acceptance checks PASS** with
  those measured numbers,
- a full spare set of printed auger segments, a spare sleeve, spare packing and
  spare gaskets are in the box,
- and the flush drill has been done twice, timed, under 5 minutes.

Then plan the day as: **12 posts ≈ 29 min of pumping, 7 hopper loads, and a
flush at every break longer than 20 minutes.** The pumping is the short part.

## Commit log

2026-09-06 tube-filler: initial design output
    [adapter_plate.dxf, adapter_plate.step, auger_scavenger_p65_L65.stl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]
2026-09-06 Square PTR posts, assembly export, and the layout errors it found
    The twelve posts are 3x3 square PTR, not round tube. post_shape / post_side
    switch the bore area (side^2 vs pi/4 d^2), so a post holds 29.5 L and the job
    is 354 L, not 278 -- 4.7 sacks of cement, not 3.7. calcs sections 1 and 10 and
    the BOM consumables all follow from it. The post drill jigs become L-section
    corner channels registering on two adjacent faces, since a vee on a flat face
    touches two arbitrary lines and rocks; the V-saddle branch is kept for
    post_shape="round" and both share one datum convention. Barrel stock is now
    documented and checked as independent of post stock -- the README had listed
    barrel_wall as driving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
    [adapter_plate.dxf, adapter_plate.step, auger_scavenger_p65_L65.stl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]
2026-09-07 Fit coupons, and one clearance parameter behind every printed fit
    out/fit_coupons.stl is one plate of 20 coupons -- four ladders of five rungs,
    each rung embossed with its own value: the auger hub bore and cross-pin hole on
    the drive shaft, the post-jig corner channel on square PTR, a template drill
    bushing on its bit, and the dust-cap barb in a 1" NPT coupling. Each coupon is
    modelled in the same print orientation as the part it stands for; a fit
    measured on a flat face does not transfer to a 45-degree one.
    print_clearance (0.25 mm diametral) now drives every printed feature that meets
    real steel: auger bore and pin, every jig register face on tube and on square
    post, every drill bushing,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
    [adapter_plate.dxf, adapter_plate.step, auger_scavenger_p74_L74.stl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]
2026-09-17 Barrel confirmed, and the auger bore taken off the coupon loop
    The barrel stock is bought: McMaster 6045N87, 3" OD x 0.120" wall, ID 2.76",
    ERW ASTM A513 Type 1, 3 ft, $42.13. That is 76.2 / 3.05 / 70.1 mm, which is
    exactly what params.py already carried -- so no dimension moved. What changed
    is status: barrel_od and barrel_wall are CONFIRMED, not measure-first, and they
    are off the TBD list.
    params.py
    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
    [auger_scavenger_p74_L74.stl, auger_segment_p124_SPARE.stl, auger_segment_p74.stl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]
2026-09-19 Slim the auger pin boss: it was metering the pump, and nobody was checking
    The cross-pin boss is a local restriction sitting in the feed channel, and for
    three revisions it was a plain 56 x 22 cylinder because it was sized for the pin
    and nothing looked at what it did to the flow.
    56 mm in a 70.1 bore leaves 61% of the plain-hub free area. calcs section 5 was
    reporting an overfeed of 1.54x -- correctly, for the plain hub -- while the LOCAL
    overfeed at each of the three boss stations was 0.58x. The screw metered above
    the stator's swallow everywhere except the three places it mattered, and starved
    there. A screw that starves anywhere starves; the pump sees the pinch, not the
    mean. That i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
    [auger_scavenger_p74_L74.stl, auger_segment_p124_SPARE.stl, auger_segment_p74.stl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]
